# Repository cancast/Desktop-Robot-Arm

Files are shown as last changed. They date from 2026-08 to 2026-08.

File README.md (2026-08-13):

<p align="center">
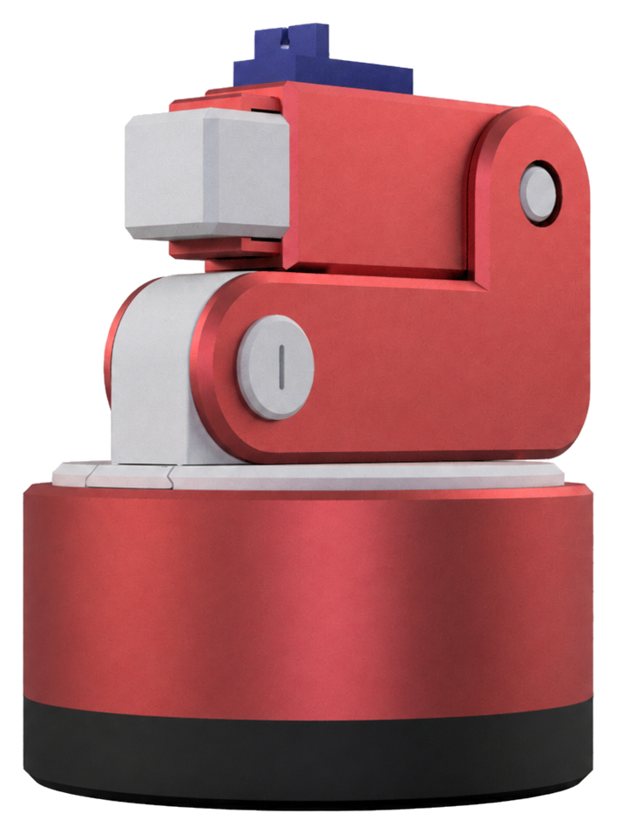
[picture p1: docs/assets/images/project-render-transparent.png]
Desktop Robot Arm 3D model
  
</p>
<h1 align="center">Desktop Robot Arm</h1>

<p align="center">
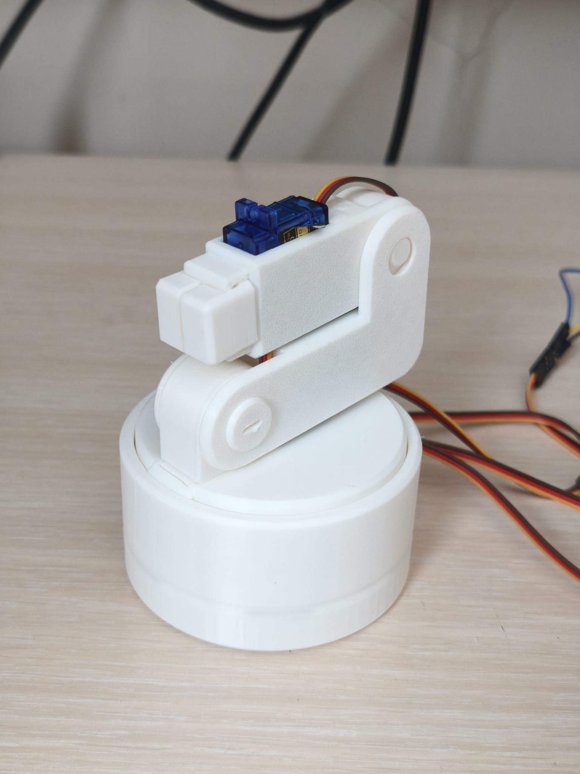
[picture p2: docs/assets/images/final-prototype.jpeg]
Desktop Robot Arm prototype
  
</p>

A compact, 3D-printed desktop robot arm built around an ESP32-C3 Mini and four SG90 servo motors. The arm creates its own Wi-Fi network and can be controlled from a phone or computer through a browser-based joystick—no separate app or internet connection is required.

This repository contains individual STL files, a ready-to-open 3MF print project, PlatformIO firmware, and reference images for the working prototype.

> [!IMPORTANT]
> This is a prototype rather than a finished consumer product. Keep hands clear of the gears and joints while it is powered, supervise it during use, and disconnect power before making mechanical or electrical changes.

## Features

- Compact, single-level rotating base with an internal ring gear
- 3D-printable body, arm, transmission, and gripper parts
- Three continuous-rotation servos for the base and arm movement
- One 180° servo for opening and closing the gripper
- ESP32-hosted responsive web interface
- Two-axis on-screen joystick with automatic stop on release
- Direct Wi-Fi access-point operation; no router or cloud service required

## How It Works

The ESP32-C3 creates a local Wi-Fi access point and serves the control page stored in the firmware. Joystick commands are sent to the ESP32 over HTTP. The X axis drives the rotating base, the Y axis drives both arm motors, and the **Gripper** button controls the fourth servo.

The mechanical design uses a ring gear in the base and helical gears in the arm to redirect the servos' rotation while keeping the assembly compact.

<p align="center">
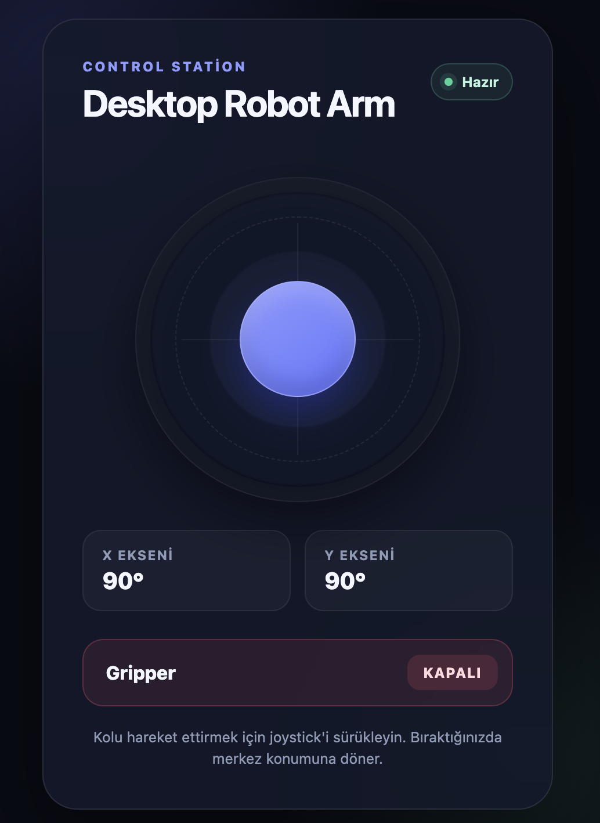
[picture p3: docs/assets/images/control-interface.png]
Robot arm web interface
  
</p>

## Demo

[▶ Watch the Desktop Robot Arm demonstration on YouTube](https://youtube.com/shorts/cK7WrAel_FE?feature=share)

## Repository Contents

```text
.
├── docs/
│   ├── desktop-robot-arm-assembly-guide.md
│   └── assets/
│       ├── assembly/
│       ├── animations/
│       │   └── desktop-robot-arm-demo.gif
│       ├── images/
│       │   ├── control-interface.png
│       │   ├── final-prototype.jpeg
│       │   ├── project-render-transparent.png
│       │   └── wiring-diagram.png
├── firmware/
│   ├── platformio.ini
│   └── src/main.cpp
└── mechanical/
    ├── desktop-robot-arm.3mf
    └── stl-files/
        └── *.stl
```

- `mechanical/desktop-robot-arm.3mf` contains all 17 printable parts arranged on one build plate together with the saved slicer profile.
- The individual STL files in [`mechanical/stl-files/`](mechanical/stl-files/) can be imported separately when a different plate arrangement or slicer is preferred.
- `firmware/` is a PlatformIO project targeting the ESP32-C3 DevKitM-1 environment with the Arduino framework.
- `docs/assets/` contains the documentation images, assembly illustrations, and animation.

## Bill of Materials

### Electronics

- 1 × ESP32-C3 Mini development board
- 3 × continuous-rotation (360°) SG90 servo motors
- 1 × positional (180°) SG90 servo motor
- 1 × regulated 5 V, 3 A power adapter
- 1 × DC barrel-jack screw terminal compatible with the adapter
- 1 × breadboard
- Jumper wires

### Mechanical

- [`desktop-robot-arm.3mf`](mechanical/desktop-robot-arm.3mf), or all individual STL files in [`mechanical/stl-files/`](mechanical/stl-files/)
- Suitable screws and fasteners for the servos
- 3D printer and filament

## Wiring

<table align="center">
  <thead>
    <tr>
      <th>Function</th>
      <th>Servo type</th>
      <th>ESP32-C3 signal pin</th>
    </tr>
  </thead>
  <tbody>
    <tr>
      <td>Base rotation</td>
      <td>Continuous rotation</td>
      <td align="center">GPIO 5</td>
    </tr>
    <tr>
      <td>Arm servo 1</td>
      <td>Continuous rotation</td>
      <td align="center">GPIO 6</td>
    </tr>
    <tr>
      <td>Arm servo 2</td>
      <td>Continuous rotation</td>
      <td align="center">GPIO 7</td>
    </tr>
    <tr>
      <td>Gripper</td>
      <td>180° positional</td>
      <td align="center">GPIO 8</td>
    </tr>
  </tbody>
</table>

<p align="center">
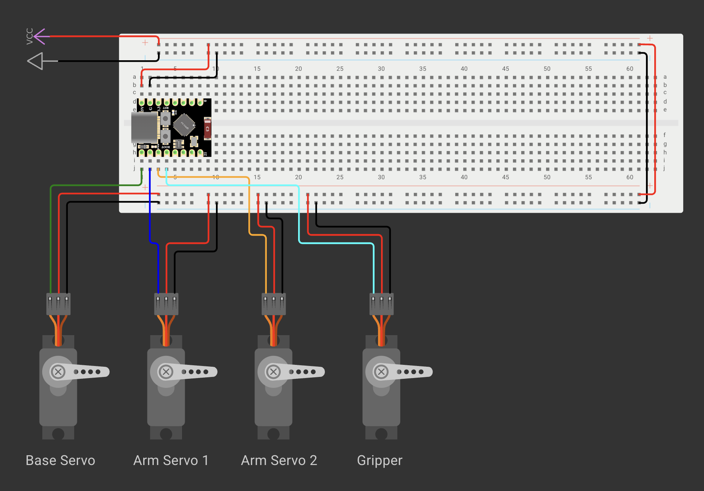
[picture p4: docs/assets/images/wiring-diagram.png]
Desktop Robot Arm wiring schema
  
</p>

The diagram shows the four servo signal connections and the shared power rails. Connect the external supply to the breadboard VCC and GND rails, power all servos from those rails, and connect the ESP32 ground to the same GND rail to provide a common reference for the PWM signals.

Power the servo motors from the regulated **5 V, 3 A external supply**, not from the ESP32's 3.3 V pin. Connect the servo supply ground and ESP32 ground together so that the PWM signals share a common reference.

> [!CAUTION]
> Check the polarity and rated voltage of every component before applying power.

## Mechanical Assembly

1. Open [`desktop-robot-arm.3mf`](mechanical/desktop-robot-arm.3mf) in Bambu Studio or another compatible slicer. Alternatively, import the individual STL files from [`mechanical/stl-files/`](mechanical/stl-files/).
2. Review the saved printer, filament, support, and plate settings before slicing. The included project was prepared with a Bambu Lab A1 profile, a 0.4 mm nozzle, 0.20 mm layer height, PLA, and supports enabled; adjust these values for your printer and material.
3. Print all parts and remove supports and print residue.
4. Follow the illustrated [`desktop-robot-arm-assembly-guide.md`](docs/desktop-robot-arm-assembly-guide.md).

At a high level, assembly consists of the following stages:

1. Install the arm and gripper servos, then join the geared arm modules.
2. Fit the gear cover and lower arm brace, then secure the joints with the printed fasteners.
3. Attach the arm to the rotating platform and install its retaining clip.
4. Install the base-rotation servo and drive gear, then join the rotating platform to the static ring-gear base.
5. Install the two gripper jaws and their synchronizing gear.
6. Turn every joint by hand and check that the gears move freely before connecting power.

## Firmware Installation

### Requirements

- [Visual Studio Code](https://code.visualstudio.com/) with the [PlatformIO IDE extension](https://platformio.org/install/ide?install=vscode), or PlatformIO Core
- A data-capable USB cable
- An ESP32-C3 Mini compatible with PlatformIO's `esp32-c3-devkitm-1` board definition

The required Arduino Servo library is declared in `firmware/platformio.ini` and will be installed automatically by PlatformIO.

### Upload with PlatformIO IDE

1. Open the [`firmware`](firmware/) folder in Visual Studio Code.
2. Connect the ESP32-C3 Mini over USB.
3. Select the **esp32-c3-devkitm-1** PlatformIO environment.
4. Run **Upload**. PlatformIO should detect the connected serial port automatically.
5. Open the serial monitor at **115200 baud** to see the access-point IP address.

### Upload with PlatformIO Core

From the repository root:

```bash
cd firmware
pio run --target upload
pio device monitor --baud 115200
```

If PlatformIO cannot detect the board automatically, list the available serial ports with `pio device list` and pass the correct port to the upload or monitor command.

## Using the Robot Arm

1. Place the robot on a stable surface and make sure the joints can move safely.
2. Apply power to the servo supply and ESP32.
3. On a phone or computer, connect to the Wi-Fi network:
   - **SSID:** `Desktop-Robot-Arm`
   - **Password:** `123456789`
4. Open the IP address printed in the serial monitor. With the default ESP32 SoftAP configuration this is normally `http://192.168.4.1/`.
5. Drag the joystick to rotate the base and move the arm.
6. Release the joystick to stop the three continuous-rotation servos.
7. Use the **Gripper** button to open or close the gripper.

The Wi-Fi name and password can be changed near the top of [`firmware/src/main.cpp`](firmware/src/main.cpp).

## Calibration and Troubleshooting

### A continuous-rotation servo moves while the joystick is centered

The firmware uses a `1500 µs` pulse as the stop point. Continuous-rotation servo neutral points vary. Adjust the center value in `stopAllServos()` and the pulse range in `handleMotor()` if a servo creeps or moves unevenly.

### The ESP32 resets when the arm moves

- Use a stable 5 V supply capable of at least 3 A.
- Do not power all servos through the ESP32 board.
- Confirm that all grounds are connected together.
- Check for stalled joints, tight gears, or wiring voltage drops.

### The Wi-Fi network does not appear

- Confirm that the firmware uploaded successfully.
- Check the serial monitor at 115200 baud.
- Keep the reduced Wi-Fi transmit-power setting in the firmware; it was required for stable operation on the prototype board.
- Verify the 5 V supply under servo load.

### The arm moves in the wrong direction

Servo orientation can reverse the expected motion. Check the physical installation first; if necessary, reverse the relevant mapping in `handleMotor()`.

## Known Limitations

- The control API is plain HTTP on a local network and has no authentication beyond the Wi-Fi password.
- Servo neutral points and travel values may require calibration for different motors.
- The current web interface assumes one active operator and does not report actual joint position.
- End stops, collision detection, current limiting, and emergency-stop hardware are not implemented.

## License

The original firmware, mechanical design files, documentation, and images created for this project are released under the [MIT License](LICENSE).

The included 3MF file may embed slicer-generated printer profiles, start/end G-code, presets, trademarks, and other metadata supplied by Bambu Lab or other third-party tools. Those embedded third-party materials are not relicensed under MIT and remain subject to the terms and rights of their respective owners. Third-party libraries installed by PlatformIO are likewise governed by their own licenses.

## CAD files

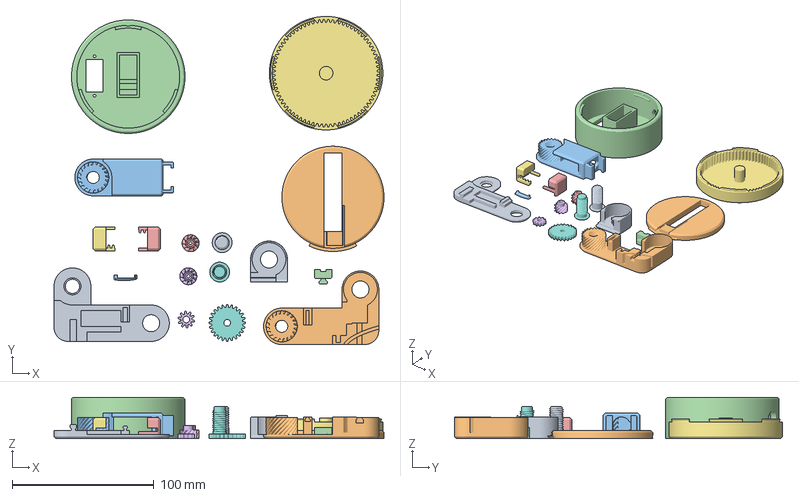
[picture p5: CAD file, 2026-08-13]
Mechanical/Desktop-Robot-Arm.3mf
232.6 x 231.3 x 29.2 mm
Arm 1 Left.stl
Arm 1 Right.stl
Arm 2 Big.stl
Arm 2 Little.stl
Gripper Left.stl
Gripper Middle Gear.stl
Gripper Right.stl
Inner Gear.stl
Joint 1.stl
Lid Big.stl
Lid Little.stl
Rotating Base.stl
Rotation Gear 1.stl
Rotation Gear 2.stl
Static Base.stl
Thread 1.stl
Thread 2.stl

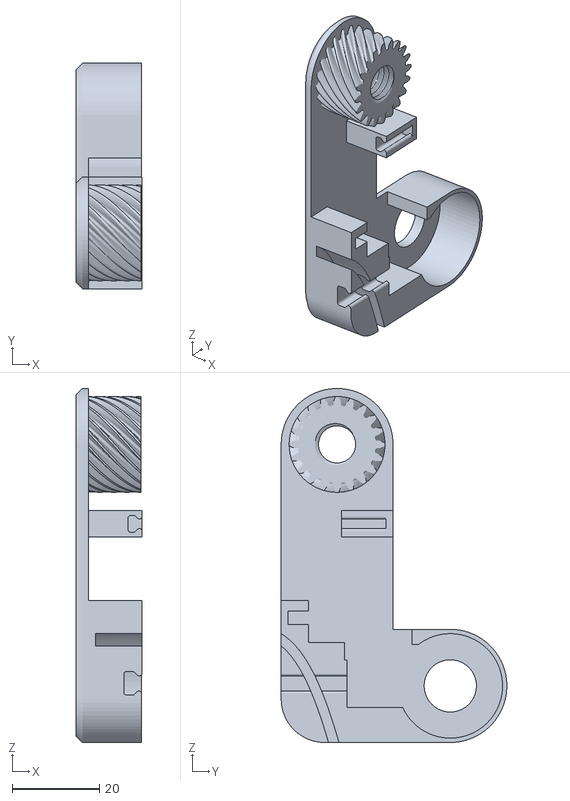
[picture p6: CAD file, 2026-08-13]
mechanical/stl-files/arm-1-right.stl
15.2 x 51.8 x 81.3

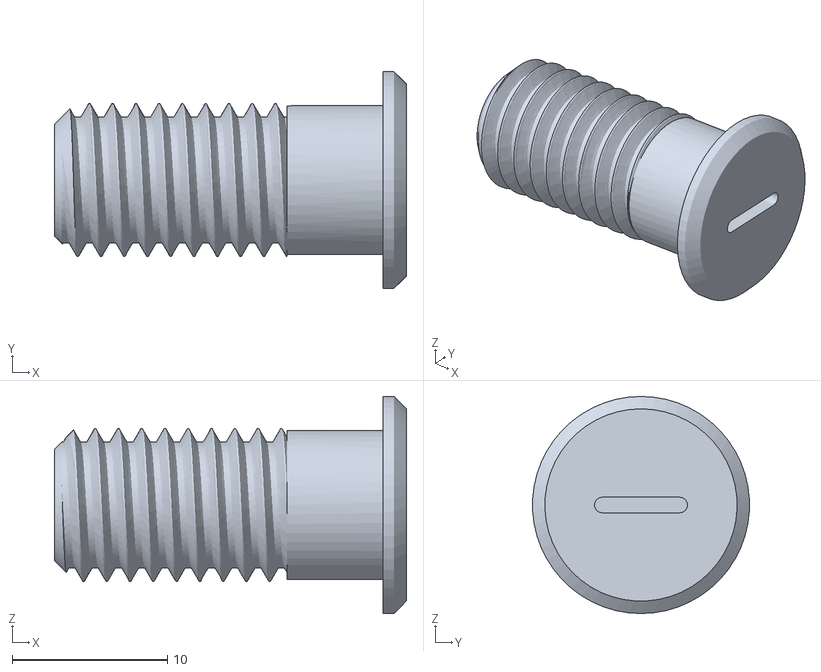
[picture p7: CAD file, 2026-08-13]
mechanical/stl-files/thread-2.stl
22.7 x 14.0 x 14.0

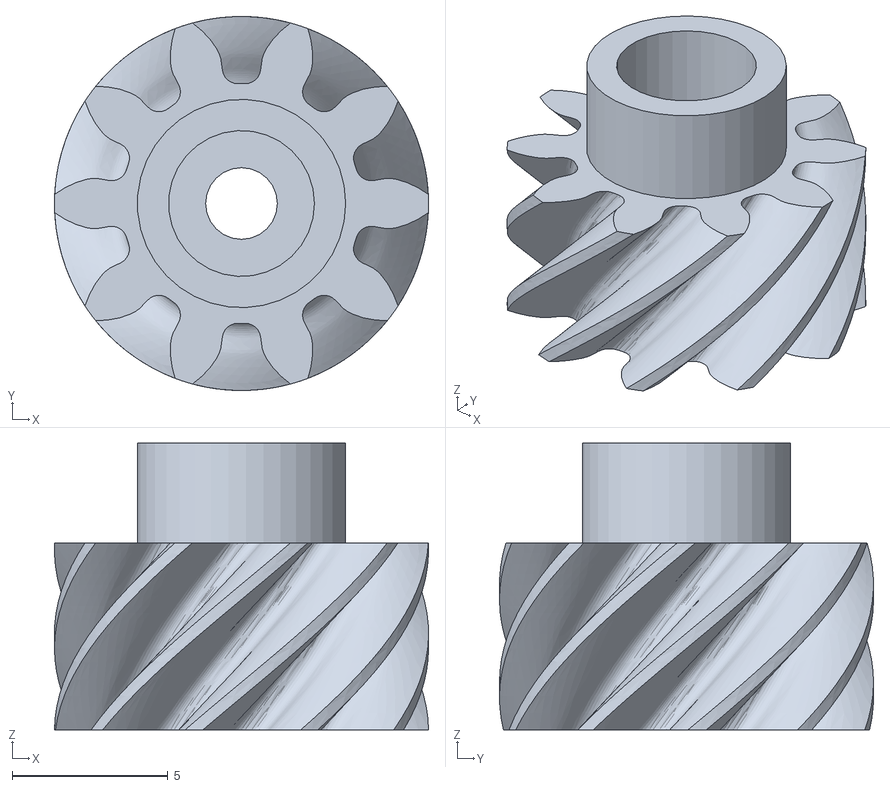
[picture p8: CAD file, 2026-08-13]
mechanical/stl-files/rotation-gear-2.stl
12.0 x 12.0 x 9.20

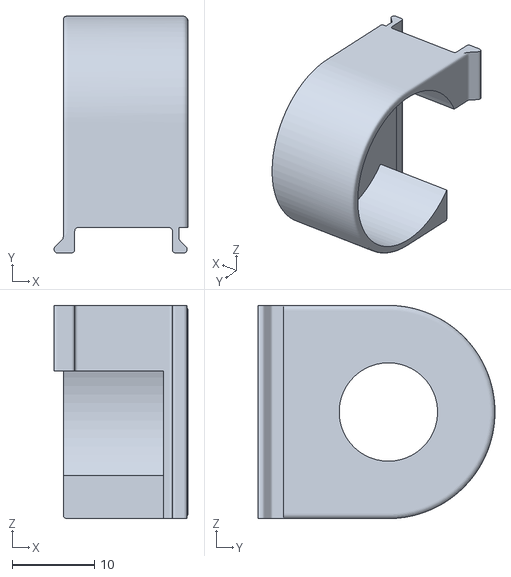
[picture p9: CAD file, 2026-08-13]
mechanical/stl-files/joint-1.stl
16.3 x 28.9 x 26.0

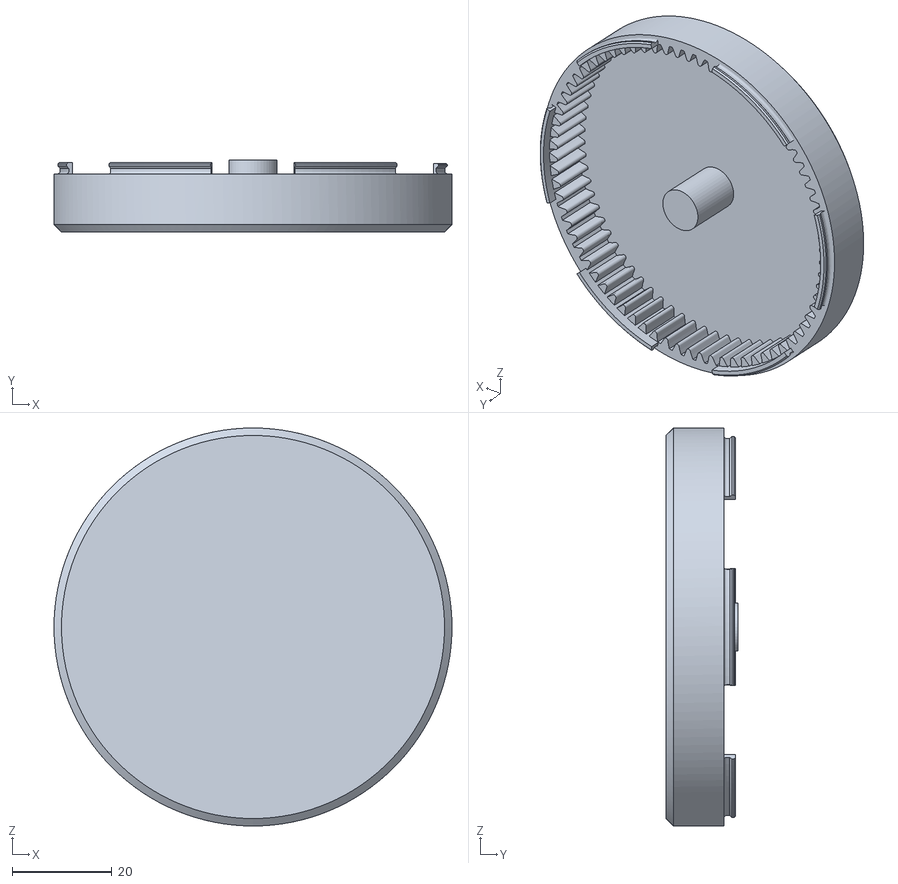
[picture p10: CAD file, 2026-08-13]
mechanical/stl-files/static-base.stl
80.0 x 14.5 x 80.0

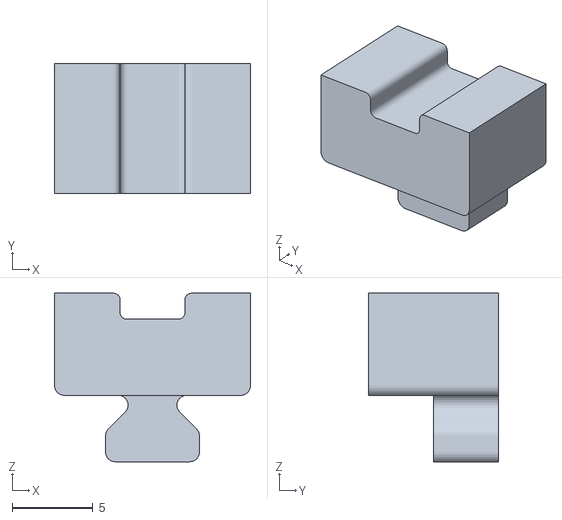
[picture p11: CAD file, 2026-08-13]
mechanical/stl-files/arm-2-little.stl
12.1 x 8.00 x 10.4

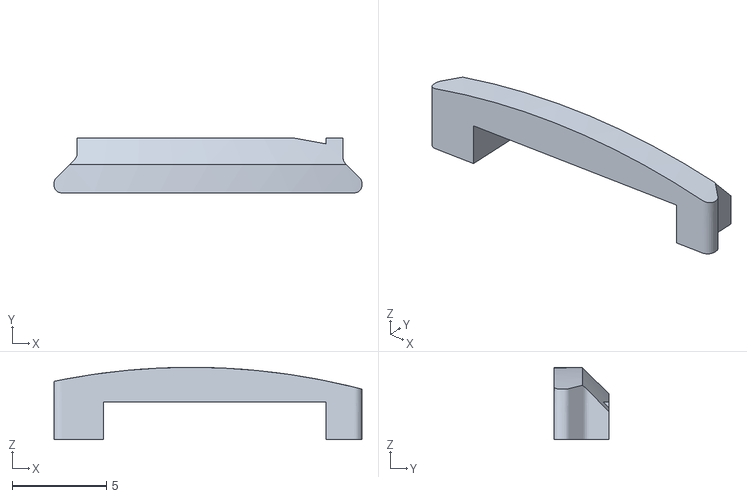
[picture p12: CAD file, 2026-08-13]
mechanical/stl-files/lid-little.stl
16.3 x 2.90 x 3.84

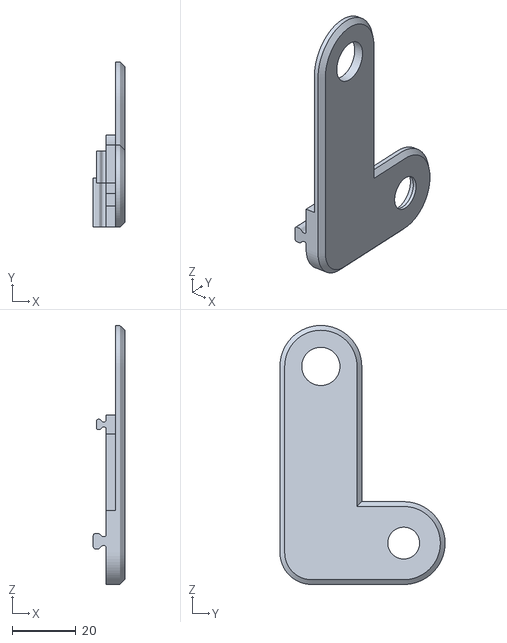
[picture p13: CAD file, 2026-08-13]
mechanical/stl-files/arm-1-left.stl
9.90 x 51.8 x 81.3

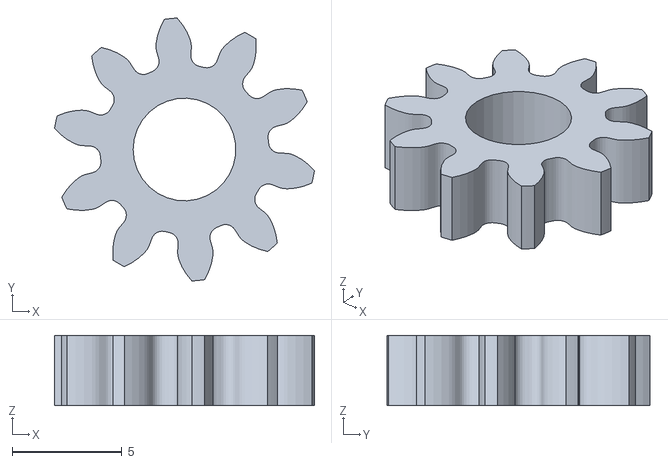
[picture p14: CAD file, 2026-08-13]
mechanical/stl-files/gripper-middle-gear.stl
11.8 x 12.0 x 3.20

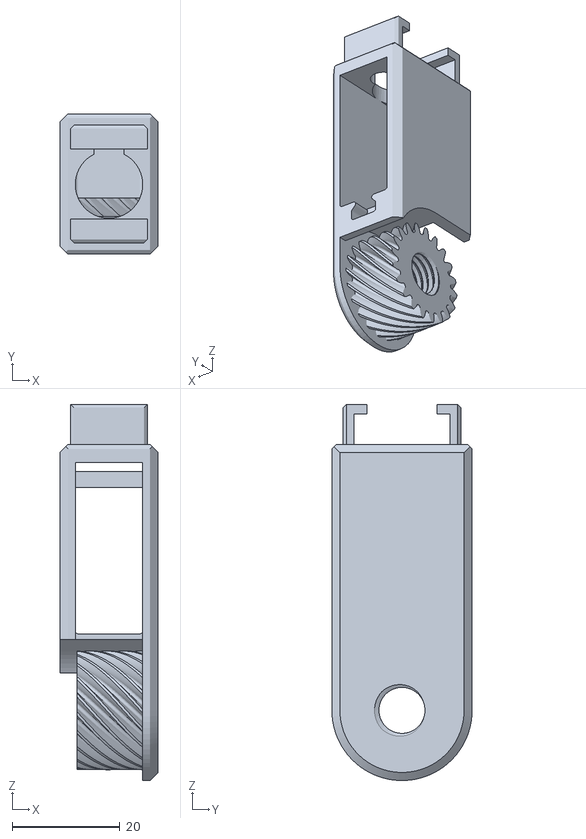
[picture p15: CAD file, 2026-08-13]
mechanical/stl-files/arm-2-big.stl
18.2 x 26.0 x 69.6

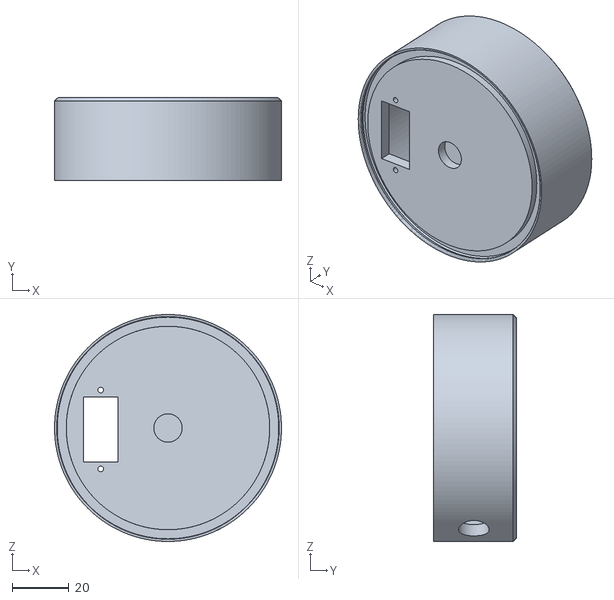
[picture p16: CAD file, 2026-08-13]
mechanical/stl-files/rotating-base.stl
80.0 x 29.2 x 80.0

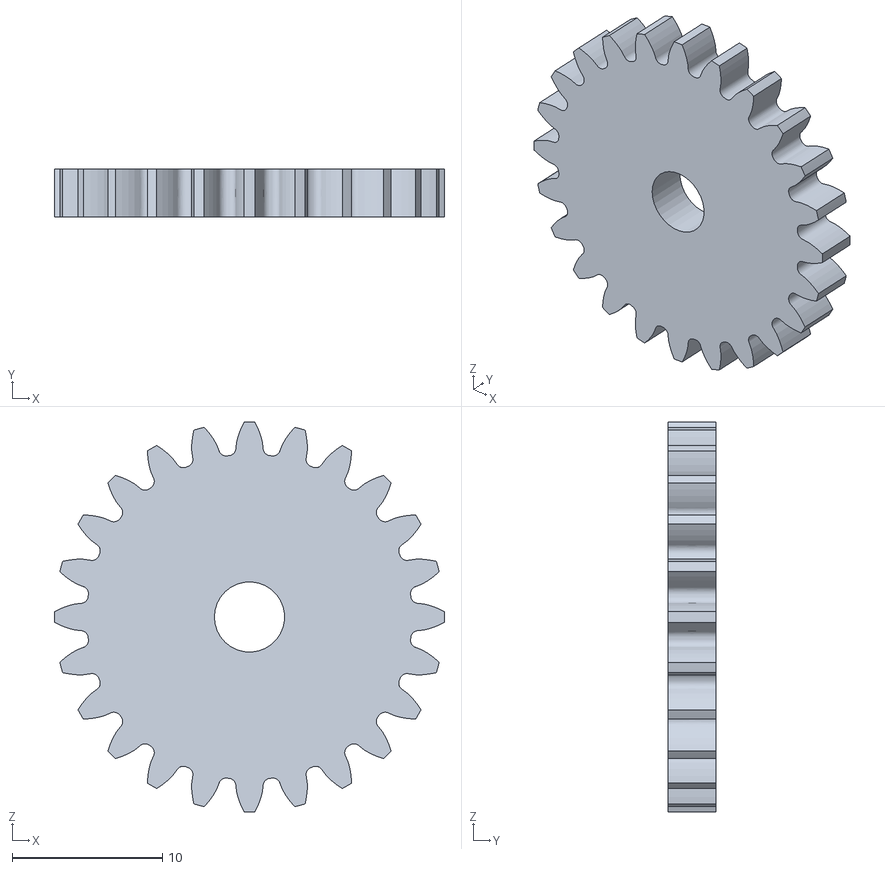
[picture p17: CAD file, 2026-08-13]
mechanical/stl-files/inner-gear.stl
26.0 x 3.20 x 26.0

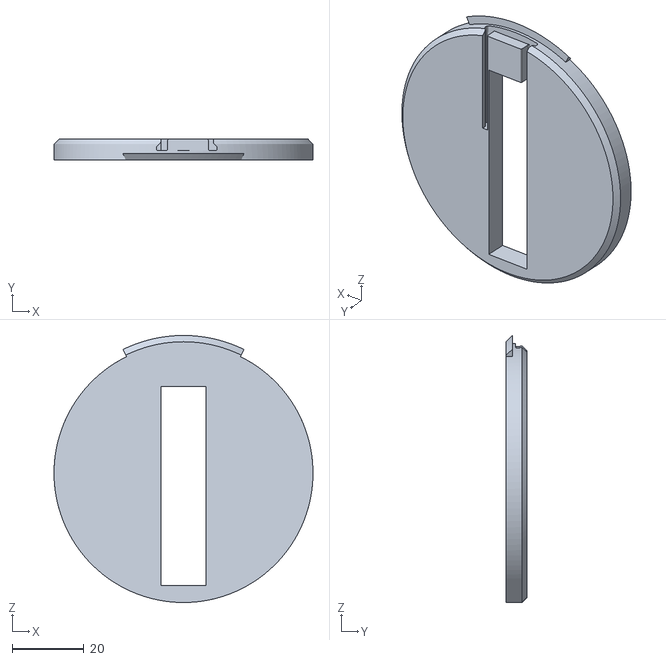
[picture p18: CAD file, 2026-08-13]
mechanical/stl-files/lid-big.stl
72.0 x 5.85 x 74.2

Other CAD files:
mechanical/stl-files/thread-1.stl
mechanical/stl-files/rotation-gear-1.stl
mechanical/stl-files/gripper-left.stl
mechanical/stl-files/gripper-right.stl

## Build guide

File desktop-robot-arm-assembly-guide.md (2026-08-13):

# Desktop Robot Arm Assembly Guide

This guide explains how to assemble the 3D-printed Desktop Robot Arm using the supplied assembly illustrations. Read the complete guide before starting, and keep the robot disconnected from power during mechanical assembly.

## Completed Robot Preview

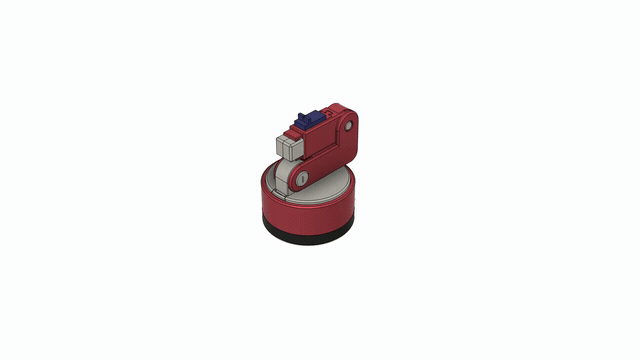
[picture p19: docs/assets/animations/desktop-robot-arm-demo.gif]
Completed Desktop Robot Arm servo movement


[▶ Watch the complete project demonstration on YouTube](https://youtube.com/shorts/cK7WrAel_FE?feature=share)

## Before You Start

Prepare the following:

- All parts printed from [`desktop-robot-arm.3mf`](mechanical/desktop-robot-arm.3mf), or from the individual STL files in [`mechanical/stl-files/`](mechanical/stl-files/)
- 3 × continuous-rotation SG90 servo motors
- 1 × 180° SG90 servo motor for the gripper
- The screws supplied with the servos
- A small Phillips screwdriver
- A deburring tool, craft knife, or fine sandpaper for carefully cleaning print residue

Before assembly:

1. Remove supports, brims, and loose material from every printed part.
2. Check that the gears turn freely and that shafts fit their corresponding holes.
3. Route servo cables away from gears and joint openings.
4. Do not force a tight part. Lightly clean or sand the mating surface and test it again.
5. Keep all servos unpowered until the mechanical movement has been checked by hand.

## Printing the Parts

The recommended starting point is [`mechanical/desktop-robot-arm.3mf`](mechanical/desktop-robot-arm.3mf). It contains all 17 mechanical parts arranged on a single build plate and retains the slicer settings used when the project was created.

The included project uses a Bambu Lab A1 profile with a 0.4 mm nozzle, 0.20 mm layer height, PLA, a textured PEI plate, and supports enabled. Before printing, open the project in Bambu Studio or another compatible slicer and verify every setting against your own printer, build plate, and filament. Rearrange the parts or use the individual STL files in [`mechanical/stl-files/`](mechanical/stl-files/) if the complete plate does not fit your printer.

### Slicer Estimate for the Included Plate

The following values come from the saved slicer estimate and may change with the printer, filament profile, support settings, or plate arrangement:

| Estimate | Value |
| --- | ---: |
| Total filament | 36.91 m / 110.08 g |
| Model filament | 35.49 m / 105.85 g |
| Preparation time | 6 min 16 sec |
| Timelapse time | 4 min 4 sec |
| Model printing time | 4 hr 35 min |
| Total time | 4 hr 46 min |

Do not send the project directly to a printer without slicing and reviewing the preview first. Check especially that supports are generated where required and that no part extends beyond the usable build area.

## Part Orientation

In each illustration, the black arrows show the insertion or joining direction. Gear teeth must mesh without being pressed tightly together. A small amount of backlash is preferable to a joint that binds.

## Step 1 — Install the First Arm Servo and Drive Gear

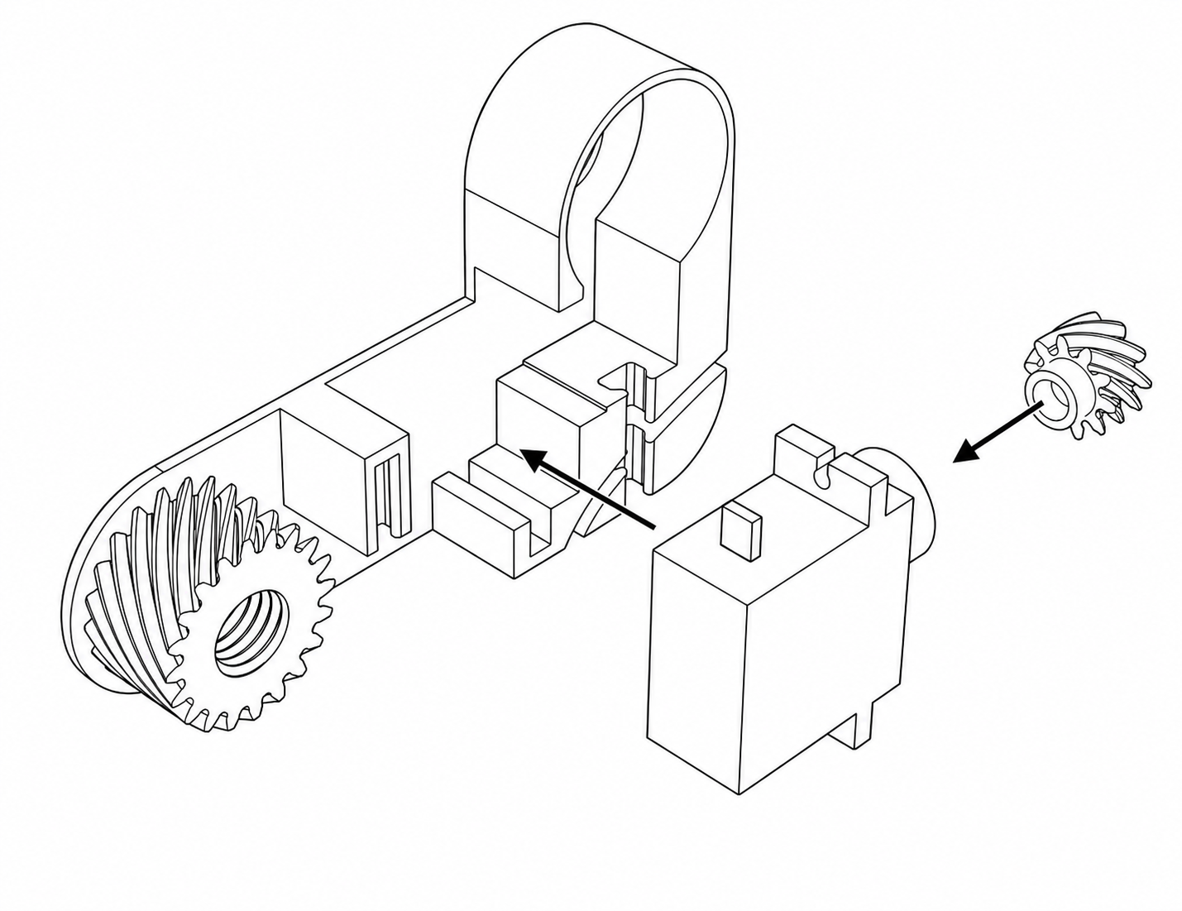
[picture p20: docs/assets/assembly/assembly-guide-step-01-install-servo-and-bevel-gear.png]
Install the first servo and drive gear


Insert the first continuous-rotation servo into the open servo pocket of the arm module. Keep its output shaft facing the large helical gear already positioned in the arm.

Fit the small helical drive gear onto the servo output shaft. Align the two gears so their angled teeth mesh across their full width. The small gear should sit straight on the shaft and must not rub against the arm wall.

Do not permanently tighten the gear until its axial position has been checked.

## Step 2 — Lower the Second Arm Servo into Its Housing

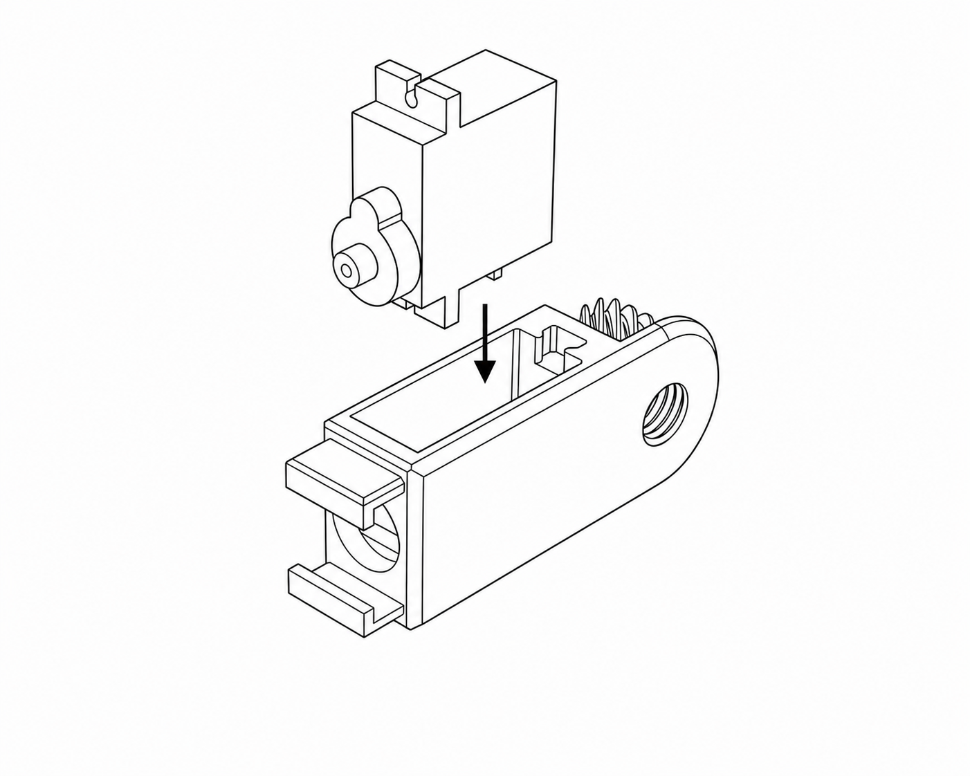
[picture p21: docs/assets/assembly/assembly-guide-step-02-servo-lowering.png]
Lower the second servo into the arm housing


Place the 180° positional servo above the rectangular opening in the other arm module. This servo will operate the gripper. Orient its output shaft toward the circular side opening, as shown, and lower the servo vertically into the pocket.

Make sure the cable exits through an unobstructed side of the housing and is not trapped underneath the servo.

## Step 3 — Install the Servo Locking Block

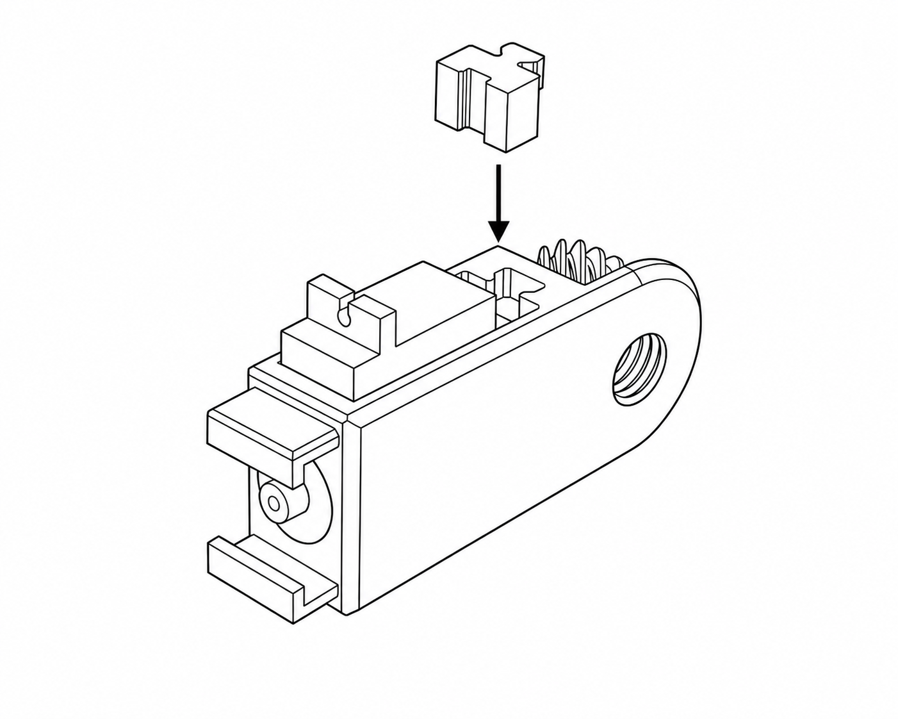
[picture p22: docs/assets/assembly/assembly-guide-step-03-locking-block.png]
Install the servo locking block


Insert the small locking block into the shaped opening behind the second servo. Match the block's keyed profile to the recess and press it down until it sits flush.

The block prevents the servo from lifting or shifting inside the arm. If it requires excessive force, remove it and clean the slot before trying again.

## Step 4 — Join the Two Arm Modules

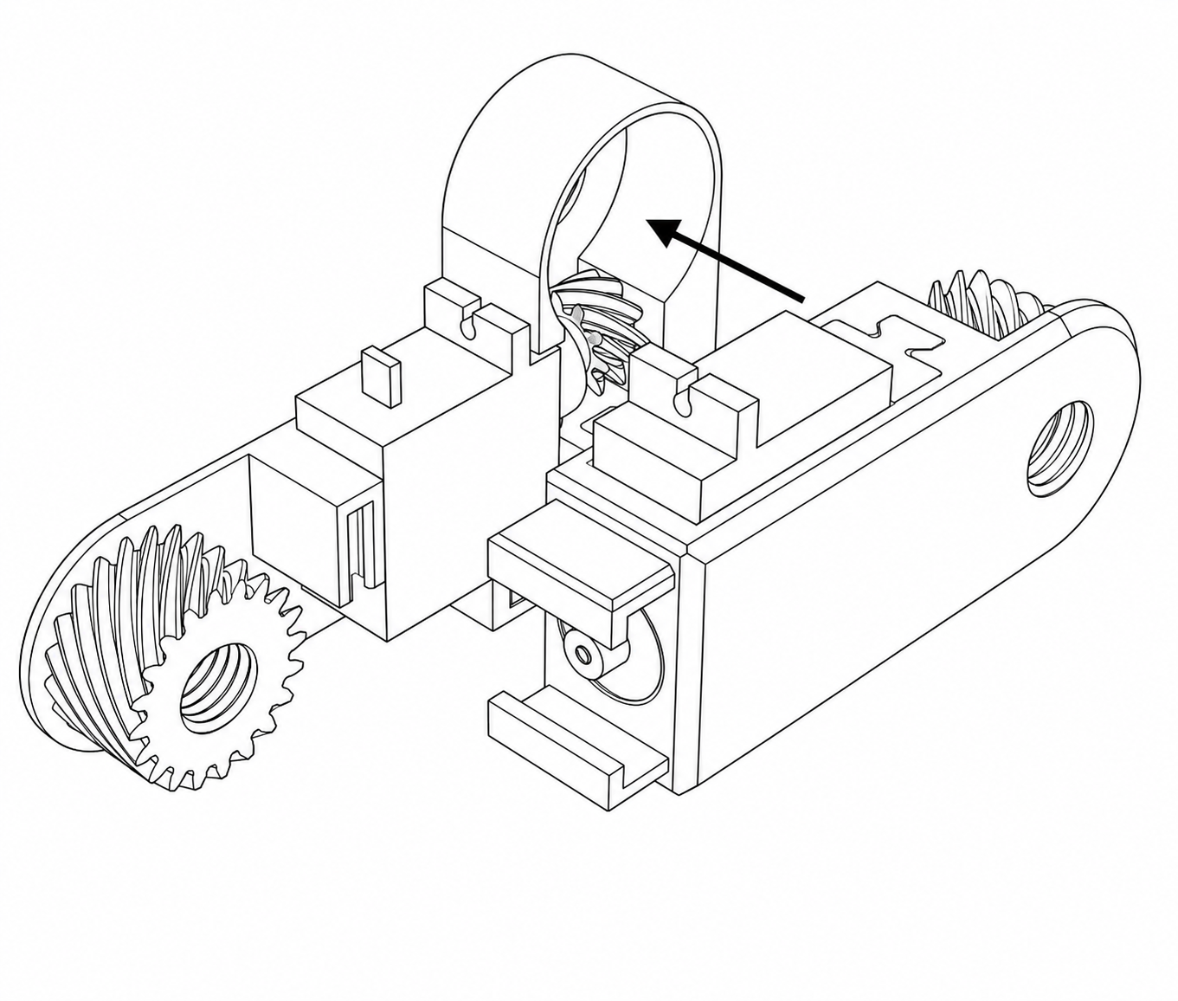
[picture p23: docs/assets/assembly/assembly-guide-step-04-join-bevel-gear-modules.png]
Join the two arm modules and mesh the gears


Bring the two completed arm modules together in the direction of the arrow. Guide the curved upper section over the small drive gear while aligning the joint faces and connection points.

As the modules meet, confirm that the small and large helical gears engage correctly.

## Step 5 — Fit the Large Gear Cover

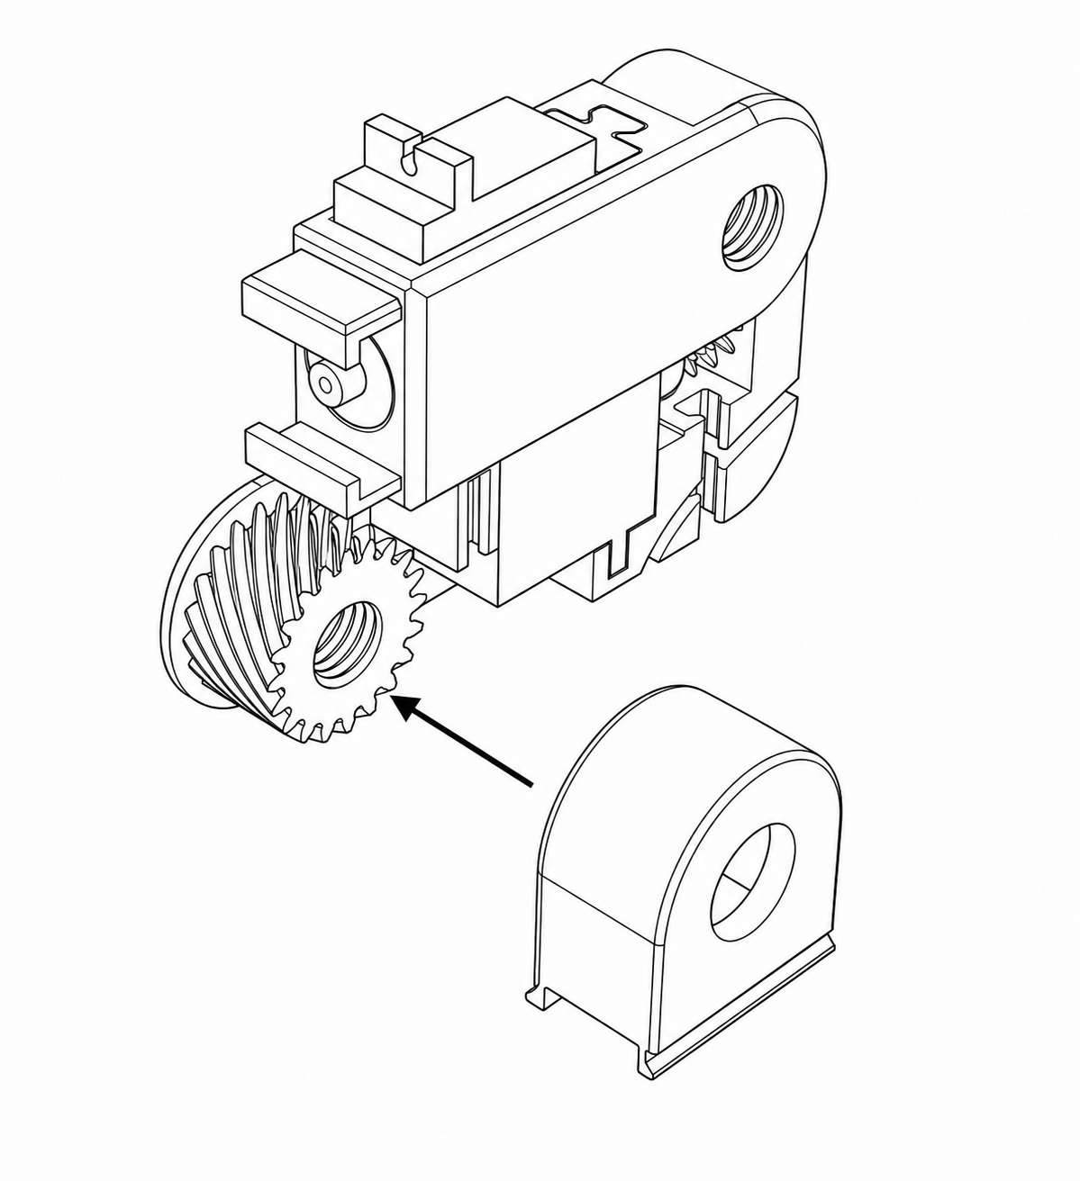
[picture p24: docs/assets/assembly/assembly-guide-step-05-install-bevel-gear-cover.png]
Fit the protective cover over the large gear


Position the rounded cover over the exposed large helical gear. Align its lower rails or tabs with the matching guides on the arm, then slide it into place in the direction shown.

The cover should enclose the gear without contacting its teeth. Check the gear again after installing the cover; it must still turn freely.

## Step 6 — Attach the Lower Arm Brace

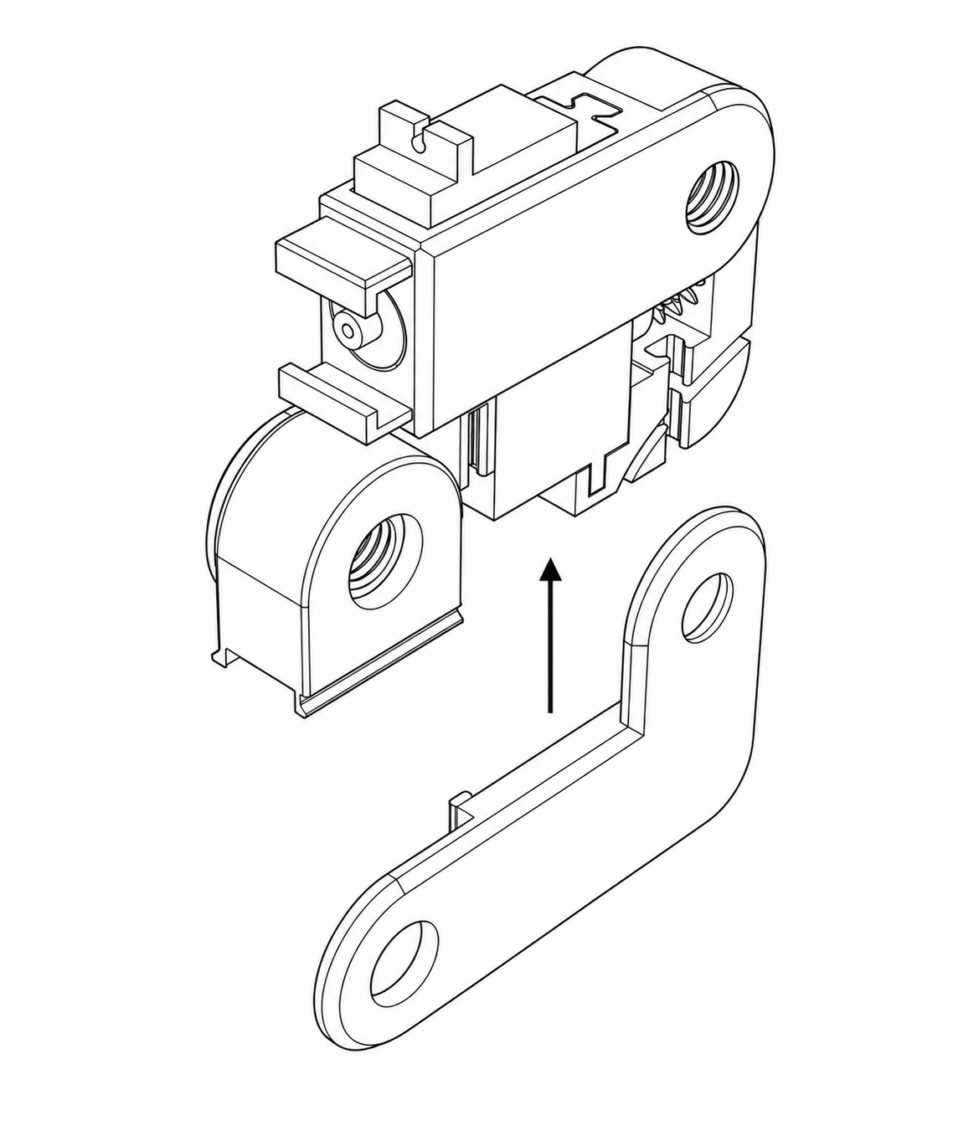
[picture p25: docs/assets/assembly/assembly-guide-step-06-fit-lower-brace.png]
Attach the lower arm brace


Align the long lower brace with the circular joint openings at both ends of the arm assembly. Raise it into position beneath the arm so that both holes line up with the corresponding threaded joint openings.

Make sure the brace is not twisted and that both sides sit flat before inserting the fasteners.

## Step 7 — Secure the Arm Joints

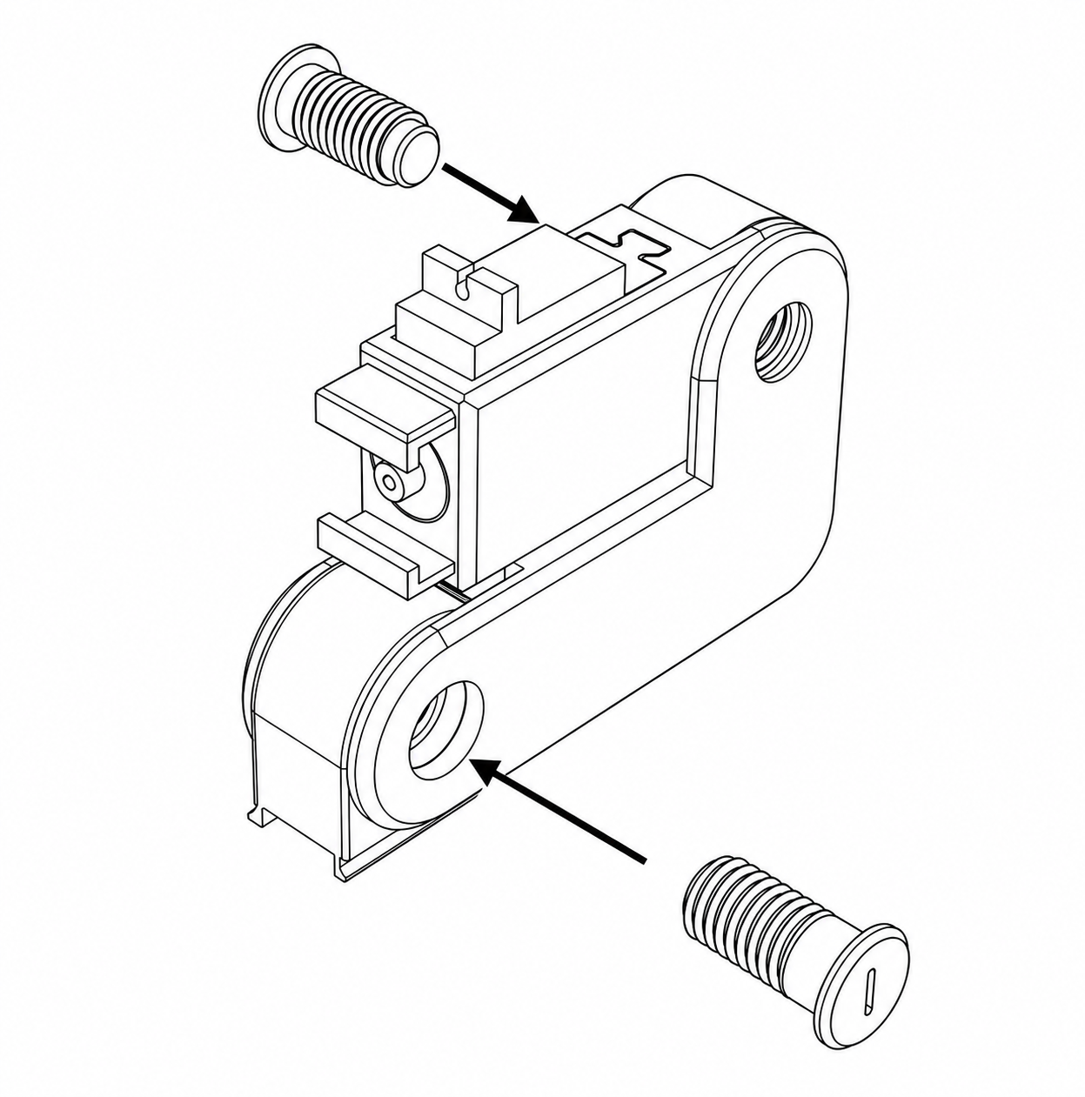
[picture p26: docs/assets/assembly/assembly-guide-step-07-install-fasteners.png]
Install the printed arm fasteners


Install the printed fasteners through the two aligned joint openings. Match each fastener to the opening shown in the illustration and tighten only until the arm sections are held together.

> [!CAUTION]
> Do not overtighten printed threads. The joints must remain able to pivot, and excessive torque can split the printed layers or clamp the mechanism.

After tightening, move the arm slowly through its available range and confirm that neither joint binds.

## Step 8 — Attach the Arm to the Rotating Platform

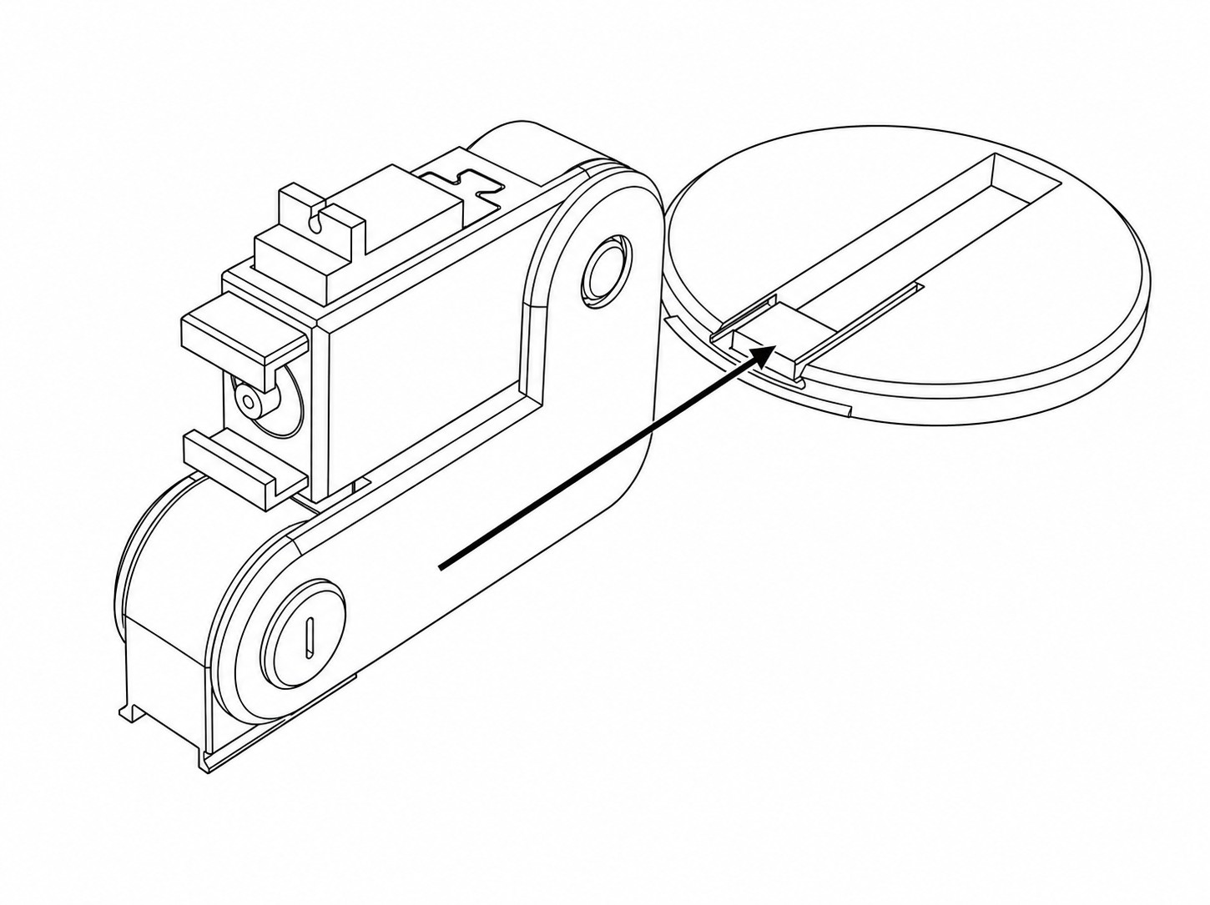
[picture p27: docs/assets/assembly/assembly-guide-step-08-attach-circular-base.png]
Slide the arm assembly onto the circular rotating platform


Align the lower rail of the arm assembly with the matching channel on the circular rotating platform. Slide the platform onto the arm in the direction shown until the end stop and retaining features line up.

Keep the platform level during insertion. Do not bend the rail or force the connection at an angle.

## Step 9 — Lock the Arm onto the Platform

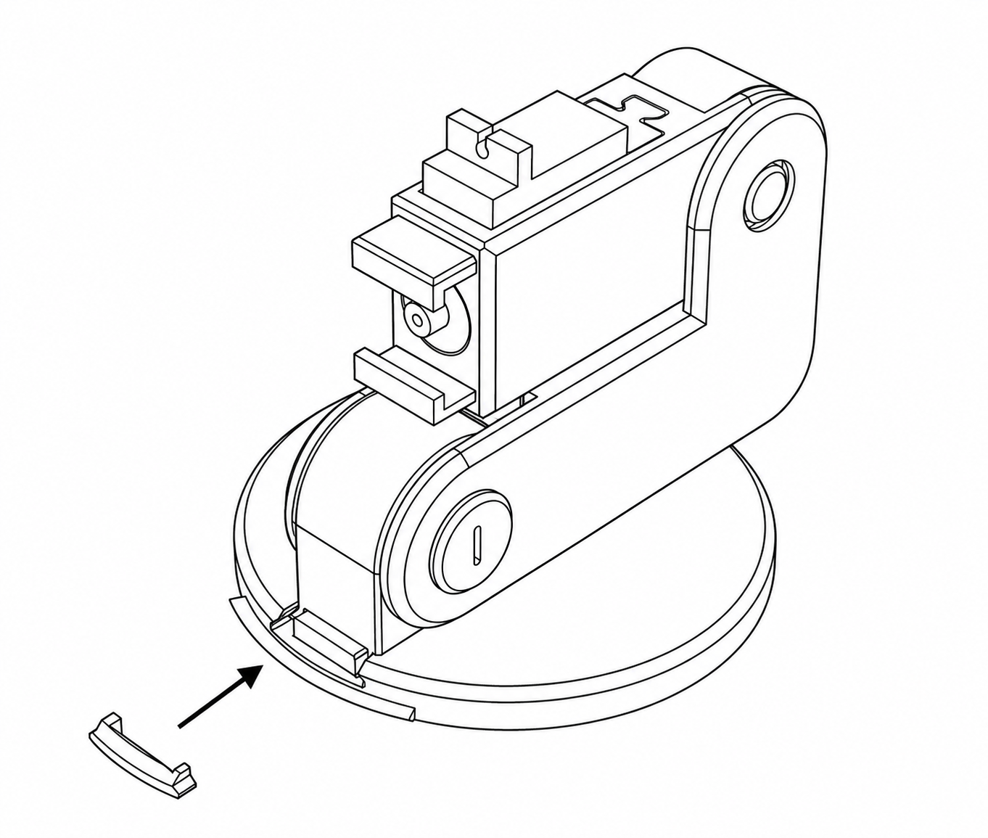
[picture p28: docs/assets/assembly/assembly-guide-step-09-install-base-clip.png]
Install the curved base retaining clip


Place the curved retaining clip into the open section of the platform's outer track. Align its end tabs with the matching slots and press or slide it into position.

Check that the clip sits level with the surrounding rim and prevents the arm assembly from sliding back out of the platform.

## Step 10 — Insert the Base-Rotation Servo

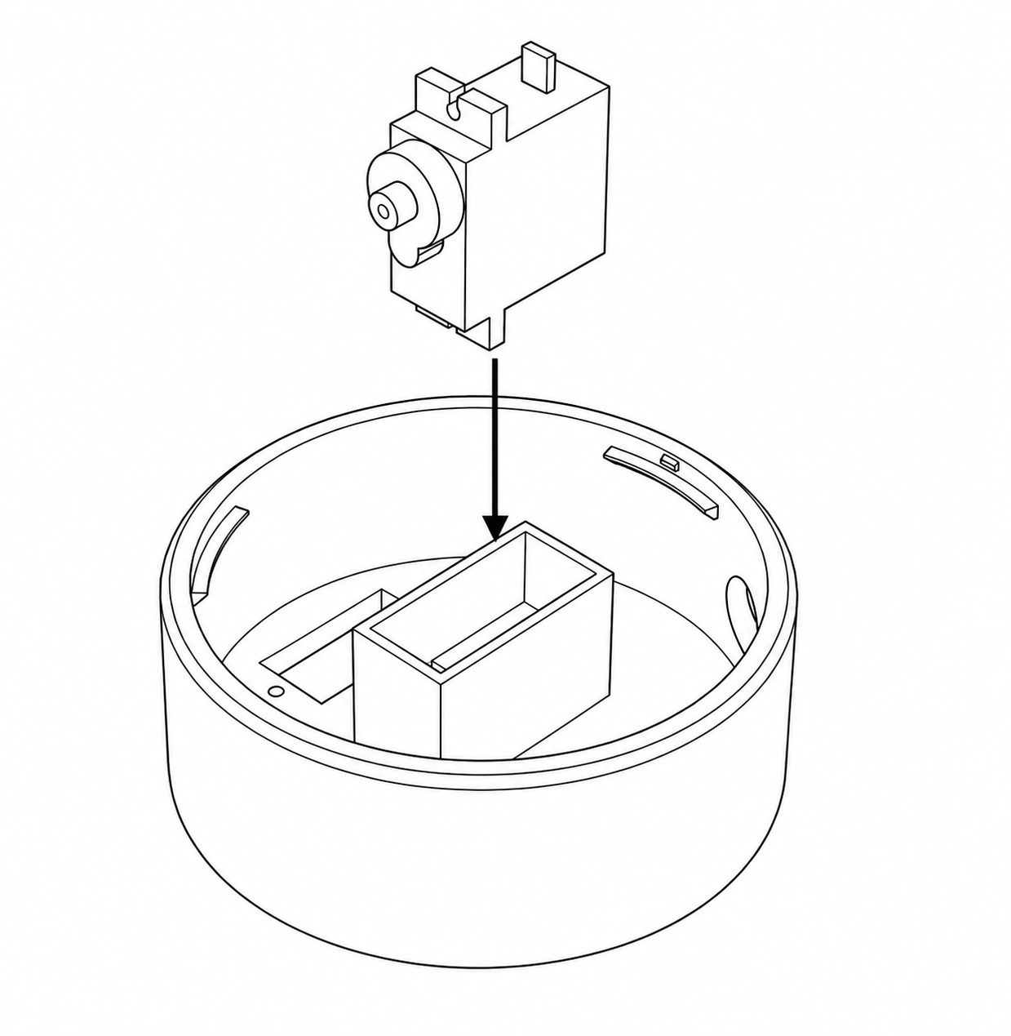
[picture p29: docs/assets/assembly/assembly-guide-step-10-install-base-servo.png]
Insert the base servo into the rotating-base housing


Lower the third continuous-rotation servo into the rectangular holder inside the rotating-base housing. Orient its output shaft toward the open side and cable passage shown in the illustration.

Route the servo wire through the available opening before the upper platform is installed. Verify that the servo is fully seated and stands square in its holder.

## Step 11 — Secure the Base Servo

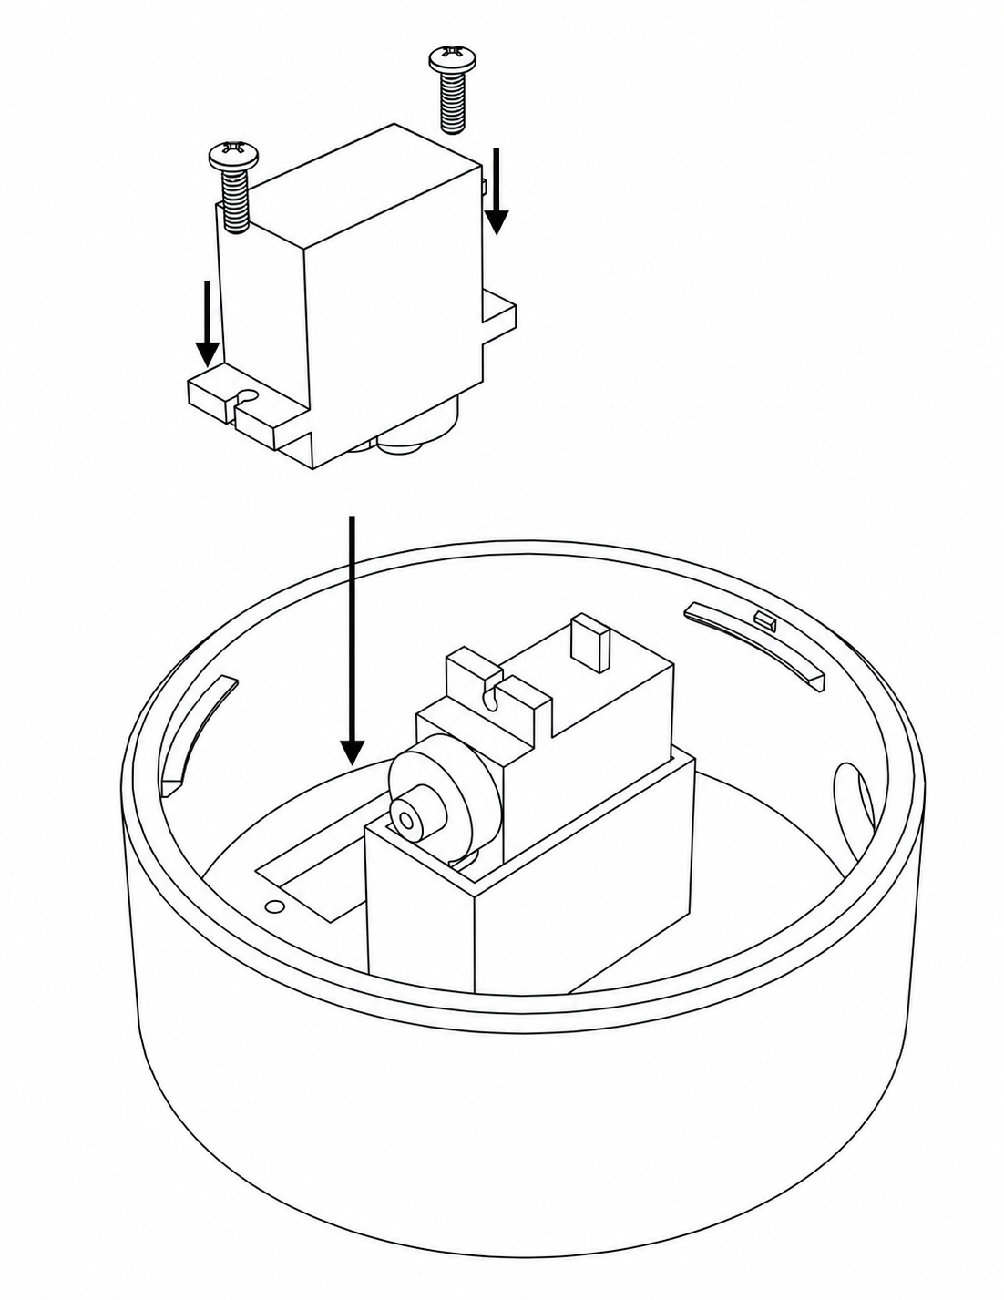
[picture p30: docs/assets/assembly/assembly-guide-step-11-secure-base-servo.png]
Secure the base servo with its mounting screws


Use the servo mounting tabs and suitable servo screws to secure the motor to its internal holder. Start both screws before tightening either one fully, then tighten them evenly.

The servo body must not move in its holder, but the screws should not crush the plastic tabs or printed mounting surface.

## Step 12 — Install the Base Drive Gear and Upper Platform

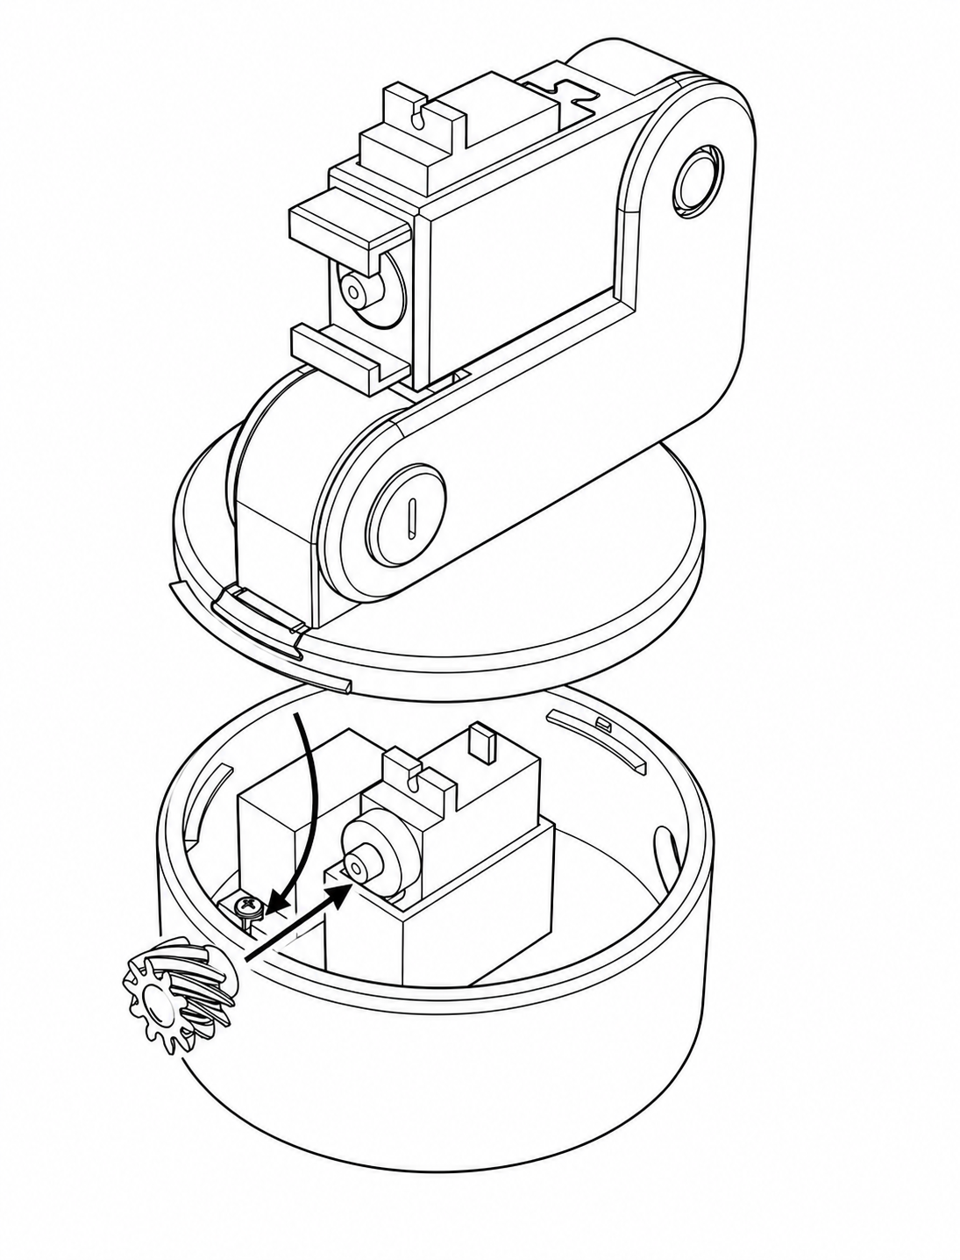
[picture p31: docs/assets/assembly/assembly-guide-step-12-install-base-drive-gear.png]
Install the base drive gear and lower the upper platform


Fit the base drive gear onto the output shaft of the servo installed in Steps 10–11. Secure it using the appropriate servo-horn screw, if required by your servo and gear fit.

Carefully lower the completed arm-and-platform assembly into the rotating-base housing. Feed the servo wires through the intended passage and make sure none of them cross the drive gear or become pinched between the two circular parts.

## Step 13 — Join the Rotating Base to the Ring-Gear Base

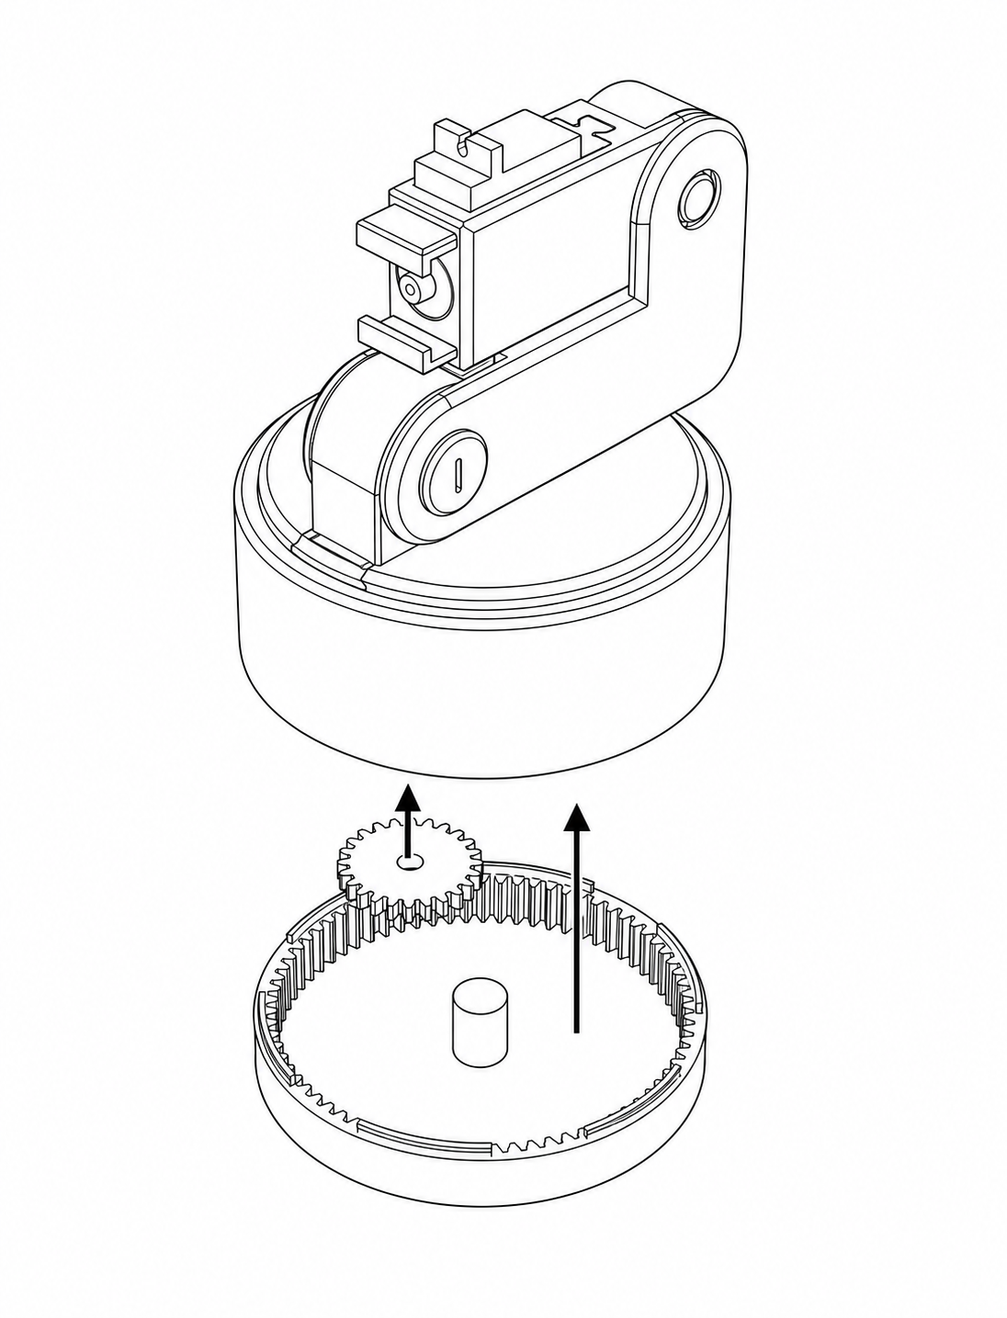
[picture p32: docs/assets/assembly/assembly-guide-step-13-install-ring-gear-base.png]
Join the rotating assembly to the static ring-gear base


Align the base drive gear with the internal ring gear in the static lower base. Lower the rotating assembly vertically over the center post while guiding the drive gear into the ring-gear teeth.

The rotating base should sit flat and remain centered. Turn it slowly by hand through a short arc and check that the drive gear stays engaged without jamming or climbing out of the ring gear.

## Step 14 — Install the Gripper Jaws

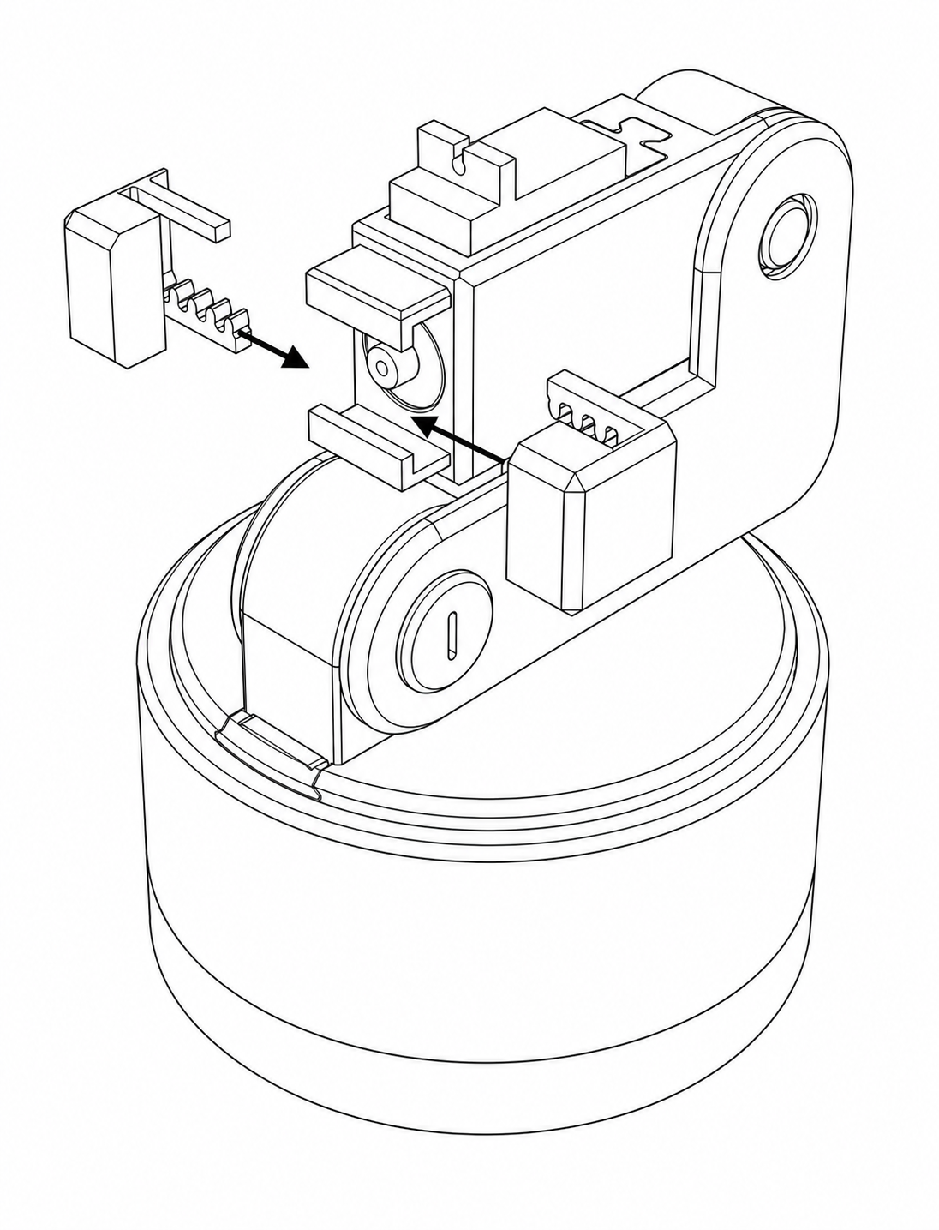
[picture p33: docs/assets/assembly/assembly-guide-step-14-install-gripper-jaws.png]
Slide the left and right gripper jaws into place


Slide the grippers into the two guides at the front of the arm. Orient both racks so their teeth face inward toward the center, as shown.

Insert the jaws evenly and position them at approximately equal distances from the center. Both jaws should slide freely along their guides without lifting or twisting.

## Step 15 — Install the Gripper Synchronizing Gear

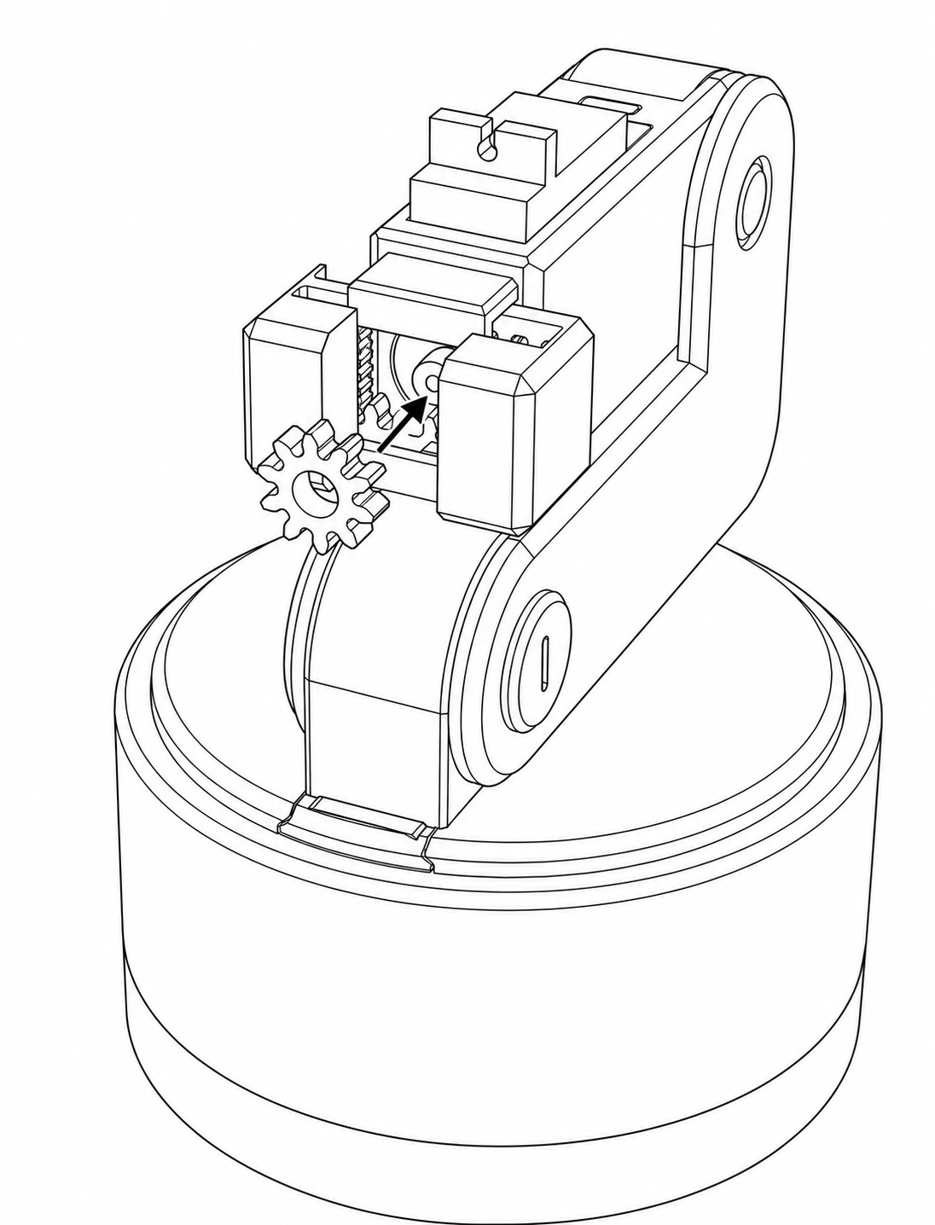
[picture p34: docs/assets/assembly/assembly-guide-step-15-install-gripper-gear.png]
Install the middle gear between the gripper jaws


Place middle gear between the two jaw racks and onto the gripper-servo output shaft. Engage the gear with both racks at the same time so that rotating it moves the jaws symmetrically in opposite directions.

Before tightening the gear, manually move the gripper through its usable range. Confirm that:

- Both jaws remain equally spaced from the center.
- The gear stays engaged with both racks.
- The jaws do not collide at the closed position.
- The racks do not leave their guides at the open position.

## Final Mechanical Checks

Before connecting the electronics or applying power:

1. Check every cover, clip, fastener, and servo mount for looseness.
2. Move each joint slowly by hand and listen for scraping or clicking.
3. Confirm that every gear remains fully engaged throughout its movement.
4. Make sure all servo cables are clear of gears, joint pivots, and the rotating-base track.
5. Place the robot on a flat, stable surface.
6. Verify that the rotating base cannot separate from the static base when lifted gently.

After the mechanical checks pass, follow the wiring, firmware installation, calibration, and operating instructions in the main [`README.md`](README.md).

> [!WARNING]
> Perform the first powered test at low load with space around the robot. Be ready to disconnect the 5 V supply if a motor stalls, a gear skips, a wire is pulled, or the ESP32 repeatedly resets.

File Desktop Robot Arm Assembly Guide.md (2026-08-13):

# Desktop Robot Arm Assembly Guide

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

## Before You Start

Prepare the following:

- All parts printed from [`Desktop-Robot-Arm.3mf`](Mechanical/Desktop-Robot-Arm.3mf), or from the individual STL files in [`Mechanical/STL Files/`](Mechanical/STL%20Files/)
- 3 × continuous-rotation SG90 servo motors
- 1 × 180° SG90 servo motor for the gripper
- The screws supplied with the servos
- A small Phillips screwdriver
- A deburring tool, craft knife, or fine sandpaper for carefully cleaning print residue

Before assembly:

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

## Printing the Parts

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

The included project uses a Bambu Lab A1 profile with a 0.4 mm nozzle, 0.20 mm layer height, PLA, a textured PEI plate, and supports enabled. Before printing, open the project in Bambu Studio or another compatible slicer and verify every setting against your own printer, build plate, and filament. Rearrange the parts or use the individual STL files in [`Mechanical/STL Files/`](Mechanical/STL%20Files/) if the complete plate does not fit your printer.

### Slicer Estimate for the Included Plate

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

## Part Orientation

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

## Step 1 — Install the First Arm Servo and Drive Gear

Install the first servo and drive gear

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

Do not permanently tighten the gear until its axial position has been checked.

## Step 2 — Lower the Second Arm Servo into Its Housing

Lower the second servo into the arm housing

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

## Step 3 — Install the Servo Locking Block

Install the servo locking block

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

## Step 4 — Join the Two Arm Modules

Join the two arm modules and mesh the gears

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

As the modules meet, confirm that the small and large helical gears engage correctly.

## Step 5 — Fit the Large Gear Cover

Fit the protective cover over the large gear

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

## Step 6 — Attach the Lower Arm Brace

Attach the lower arm brace

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

## Step 7 — Secure the Arm Joints

Install the printed arm fasteners

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

After tightening, move the arm slowly through its available range and confirm that neither joint binds.

## Step 8 — Attach the Arm to the Rotating Platform

Slide the arm assembly onto the circular rotating platform

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

## Step 9 — Lock the Arm onto the Platform

Install the curved base retaining clip

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

## Step 10 — Insert the Base-Rotation Servo

Insert the base servo into the rotating-base housing

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

## Step 11 — Secure the Base Servo

Secure the base servo with its mounting screws

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

## Step 12 — Install the Base Drive Gear and Upper Platform

Install the base drive gear and lower the upper platform

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

## Step 13 — Join the Rotating Base to the Ring-Gear Base

Join the rotating assembly to the static ring-gear base

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

## Step 14 — Install the Gripper Jaws

Slide the left and right gripper jaws into place

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

## Step 15 — Install the Gripper Synchronizing Gear

Install the middle gear between the gripper jaws

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

Before tightening the gear, manually move the gripper through its usable range. Confirm that:

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

## Final Mechanical Checks

Before connecting the electronics or applying power:

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

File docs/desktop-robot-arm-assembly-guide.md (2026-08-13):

# Desktop Robot Arm Assembly Guide

This guide explains how to assemble the 3D-printed Desktop Robot Arm using the supplied assembly illustrations. Read the complete guide before starting, and keep the robot disconnected from power during mechanical assembly.

## Completed Robot Preview

<p align="center">
  Completed Desktop Robot Arm servo movement
</p>

[▶ Watch the complete project demonstration on YouTube](https://youtube.com/shorts/cK7WrAel_FE?feature=share)

## Before You Start

Prepare the following:

- All parts printed from [`desktop-robot-arm.3mf`](../mechanical/desktop-robot-arm.3mf), or from the individual STL files in [`mechanical/stl-files/`](../mechanical/stl-files/)
- 3 × continuous-rotation SG90 servo motors
- 1 × 180° SG90 servo motor for the gripper
- The screws supplied with the servos
- A small Phillips screwdriver
- A deburring tool, craft knife, or fine sandpaper for carefully cleaning print residue

Before assembly:

1. Remove supports, brims, and loose material from every printed part.
2. Check that the gears turn freely and that shafts fit their corresponding holes.
3. Route servo cables away from gears and joint openings.
4. Do not force a tight part. Lightly clean or sand the mating surface and test it again.
5. Keep all servos unpowered until the mechanical movement has been checked by hand.

## Printing the Parts

The recommended starting point is [`mechanical/desktop-robot-arm.3mf`](../mechanical/desktop-robot-arm.3mf). It contains all 17 mechanical parts arranged on a single build plate and retains the slicer settings used when the project was created.

The included project uses a Bambu Lab A1 profile with a 0.4 mm nozzle, 0.20 mm layer height, PLA, a textured PEI plate, and supports enabled. Before printing, open the project in Bambu Studio or another compatible slicer and verify every setting against your own printer, build plate, and filament. Rearrange the parts or use the individual STL files in [`mechanical/stl-files/`](../mechanical/stl-files/) if the complete plate does not fit your printer.

### Slicer Estimate for the Included Plate

The following values come from the saved slicer estimate and may change with the printer, filament profile, support settings, or plate arrangement:

| Estimate | Value |
| --- | ---: |
| Total filament | 36.91 m / 110.08 g |
| Model filament | 35.49 m / 105.85 g |
| Preparation time | 6 min 16 sec |
| Timelapse time | 4 min 4 sec |
| Model printing time | 4 hr 35 min |
| Total time | 4 hr 46 min |

Do not send the project directly to a printer without slicing and reviewing the preview first. Check especially that supports are generated where required and that no part extends beyond the usable build area.

## Part Orientation

In each illustration, the black arrows show the insertion or joining direction. Gear teeth must mesh without being pressed tightly together. A small amount of backlash is preferable to a joint that binds.

## Step 1 — Install the First Arm Servo and Drive Gear

<p align="center">
  Install the first servo and drive gear
</p>

Insert the first continuous-rotation servo into the open servo pocket of the arm module. Keep its output shaft facing the large helical gear already positioned in the arm.

Fit the small helical drive gear onto the servo output shaft. Align the two gears so their angled teeth mesh across their full width. The small gear should sit straight on the shaft and must not rub against the arm wall.

Do not permanently tighten the gear until its axial position has been checked.

## Step 2 — Lower the Second Arm Servo into Its Housing

<p align="center">
  Lower the second servo into the arm housing
</p>

Place the 180° positional servo above the rectangular opening in the other arm module. This servo will operate the gripper. Orient its output shaft toward the circular side opening, as shown, and lower the servo vertically into the pocket.

Make sure the cable exits through an unobstructed side of the housing and is not trapped underneath the servo.

## Step 3 — Install the Servo Locking Block

<p align="center">
  Install the servo locking block
</p>

Insert the small locking block into the shaped opening behind the second servo. Match the block's keyed profile to the recess and press it down until it sits flush.

The block prevents the servo from lifting or shifting inside the arm. If it requires excessive force, remove it and clean the slot before trying again.

## Step 4 — Join the Two Arm Modules

<p align="center">
  Join the two arm modules and mesh the gears
</p>

Bring the two completed arm modules together in the direction of the arrow. Guide the curved upper section over the small drive gear while aligning the joint faces and connection points.

As the modules meet, confirm that the small and large helical gears engage correctly.

## Step 5 — Fit the Large Gear Cover

<p align="center">
  Fit the protective cover over the large gear
</p>

Position the rounded cover over the exposed large helical gear. Align its lower rails or tabs with the matching guides on the arm, then slide it into place in the direction shown.

The cover should enclose the gear without contacting its teeth. Check the gear again after installing the cover; it must still turn freely.

## Step 6 — Attach the Lower Arm Brace

<p align="center">
  Attach the lower arm brace
</p>

Align the long lower brace with the circular joint openings at both ends of the arm assembly. Raise it into position beneath the arm so that both holes line up with the corresponding threaded joint openings.

Make sure the brace is not twisted and that both sides sit flat before inserting the fasteners.

## Step 7 — Secure the Arm Joints

<p align="center">
  Install the printed arm fasteners
</p>

Install the printed fasteners through the two aligned joint openings. Match each fastener to the opening shown in the illustration and tighten only until the arm sections are held together.

> [!CAUTION]
> Do not overtighten printed threads. The joints must remain able to pivot, and excessive torque can split the printed layers or clamp the mechanism.

After tightening, move the arm slowly through its available range and confirm that neither joint binds.

## Step 8 — Attach the Arm to the Rotating Platform

<p align="center">
  Slide the arm assembly onto the circular rotating platform
</p>

Align the lower rail of the arm assembly with the matching channel on the circular rotating platform. Slide the platform onto the arm in the direction shown until the end stop and retaining features line up.

Keep the platform level during insertion. Do not bend the rail or force the connection at an angle.

## Step 9 — Lock the Arm onto the Platform

<p align="center">
  Install the curved base retaining clip
</p>

Place the curved retaining clip into the open section of the platform's outer track. Align its end tabs with the matching slots and press or slide it into position.

Check that the clip sits level with the surrounding rim and prevents the arm assembly from sliding back out of the platform.

## Step 10 — Insert the Base-Rotation Servo

<p align="center">
  Insert the base servo into the rotating-base housing
</p>

Lower the third continuous-rotation servo into the rectangular holder inside the rotating-base housing. Orient its output shaft toward the open side and cable passage shown in the illustration.

Route the servo wire through the available opening before the upper platform is installed. Verify that the servo is fully seated and stands square in its holder.

## Step 11 — Secure the Base Servo

<p align="center">
  Secure the base servo with its mounting screws
</p>

Use the servo mounting tabs and suitable servo screws to secure the motor to its internal holder. Start both screws before tightening either one fully, then tighten them evenly.

The servo body must not move in its holder, but the screws should not crush the plastic tabs or printed mounting surface.

## Step 12 — Install the Base Drive Gear and Upper Platform

<p align="center">
  Install the base drive gear and lower the upper platform
</p>

Fit the base drive gear onto the output shaft of the servo installed in Steps 10–11. Secure it using the appropriate servo-horn screw, if required by your servo and gear fit.

Carefully lower the completed arm-and-platform assembly into the rotating-base housing. Feed the servo wires through the intended passage and make sure none of them cross the drive gear or become pinched between the two circular parts.

## Step 13 — Join the Rotating Base to the Ring-Gear Base

<p align="center">
  Join the rotating assembly to the static ring-gear base
</p>

Align the base drive gear with the internal ring gear in the static lower base. Lower the rotating assembly vertically over the center post while guiding the drive gear into the ring-gear teeth.

The rotating base should sit flat and remain centered. Turn it slowly by hand through a short arc and check that the drive gear stays engaged without jamming or climbing out of the ring gear.

## Step 14 — Install the Gripper Jaws

<p align="center">
  Slide the left and right gripper jaws into place
</p>

Slide the grippers into the two guides at the front of the arm. Orient both racks so their teeth face inward toward the center, as shown.

Insert the jaws evenly and position them at approximately equal distances from the center. Both jaws should slide freely along their guides without lifting or twisting.

## Step 15 — Install the Gripper Synchronizing Gear

<p align="center">
  Install the middle gear between the gripper jaws
</p>

Place middle gear between the two jaw racks and onto the gripper-servo output shaft. Engage the gear with both racks at the same time so that rotating it moves the jaws symmetrically in opposite directions.

Before tightening the gear, manually move the gripper through its usable range. Confirm that:

- Both jaws remain equally spaced from the center.
- The gear stays engaged with both racks.
- The jaws do not collide at the closed position.
- The racks do not leave their guides at the open position.

## Final Mechanical Checks

Before connecting the electronics or applying power:

1. Check every cover, clip, fastener, and servo mount for looseness.
2. Move each joint slowly by hand and listen for scraping or clicking.
3. Confirm that every gear remains fully engaged throughout its movement.
4. Make sure all servo cables are clear of gears, joint pivots, and the rotating-base track.
5. Place the robot on a flat, stable surface.
6. Verify that the rotating base cannot separate from the static base when lifted gently.

After the mechanical checks pass, follow the wiring, firmware installation, calibration, and operating instructions in the main [`README.md`](../README.md).

> [!WARNING]
> Perform the first powered test at low load with space around the robot. Be ready to disconnect the 5 V supply if a motor stalls, a gear skips, a wire is pulled, or the ESP32 repeatedly resets.
